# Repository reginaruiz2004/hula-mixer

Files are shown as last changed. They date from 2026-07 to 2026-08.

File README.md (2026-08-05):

# Hula Mixer

Low-cost lab mixer built with Arduino Uno, L298N, and a NEMA17 stepper motor.

## Overview

DIY rotary mixer designed as a cost-effective alternative to commercial lab mixers. Built around an Arduino Uno controlling a NEMA17 stepper motor through an L298N driver, with a rocker switch for power control.

## Status

🔧 In progress — motor control validated, working on perfboard assembly and enclosure design.

## Components

- Arduino Uno R3
- L298N motor driver
- NEMA17 stepper motor (17HS4401)
- Illuminated rocker switch (3-pin, SPDT)
- 12V power supply
- Perfboard (10x7cm)

See [BOM.md](docs/BOM.md) for full parts list.

## Progress Log

- **2026-07-30:** Motor control validated with L298N (coil pairing confirmed: Black-Blue, Green-Red). Wiring diagram completed in Tinkercad. GitHub repo created.

### July 31, 2026

**Circuit Design on TinkerCad**

Key steps completed this round:

- Created a complete circuit diagram of Arduino UNO, L298N, and NEMA17 motor.

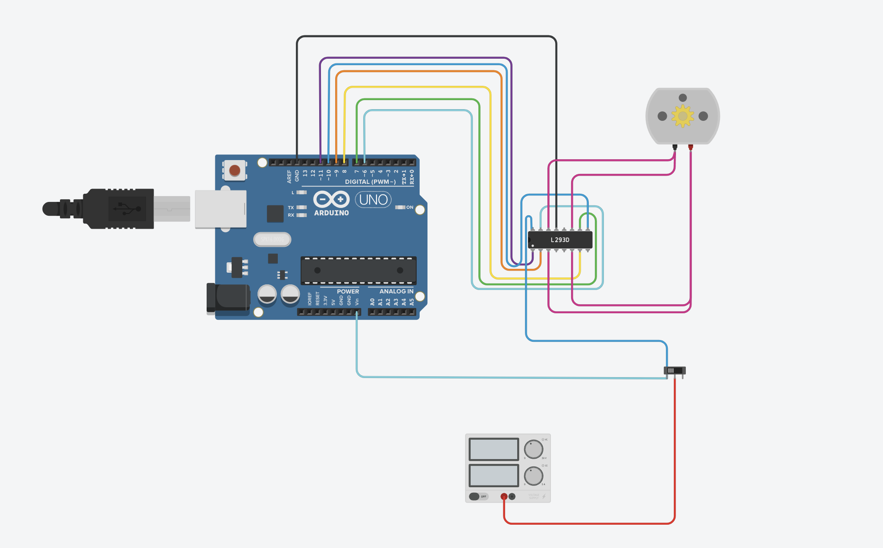
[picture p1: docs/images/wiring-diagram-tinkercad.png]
Circuit Design


### August 4, 2026

**Wooden base setup**

Key steps completed this round:

- Got a wooden base to screw in all of the hula mixer pieces.
- Drilled holes on the wooden base.
- Screwed in each hula mixer piece.
- Using hot glue, I stuck together the other electrical components like the L298N and the Arduino UNO onto a Perfboard.
- Used zip ties to hold all the coords neatly.
- Designed a 3D piece for the coord casing.

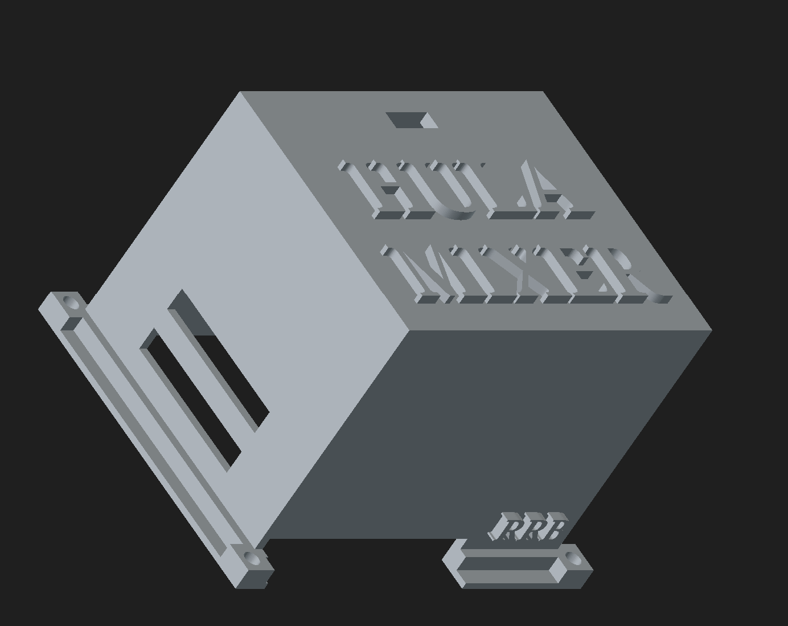
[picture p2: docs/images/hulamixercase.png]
Wiring Case

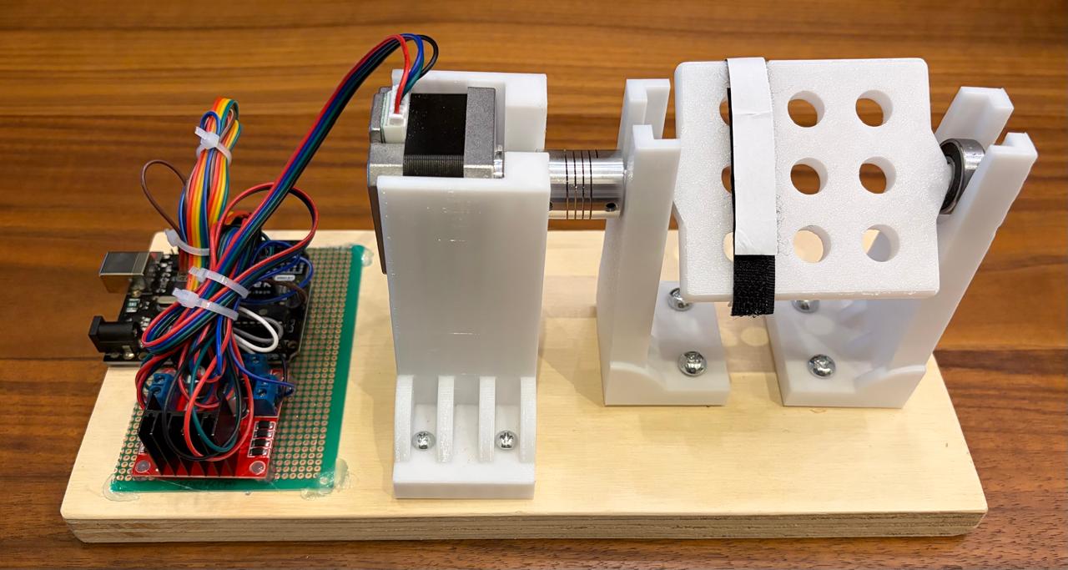
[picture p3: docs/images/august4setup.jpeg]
Hula Mixer Setup

## Documentation

- [Bill of Materials](docs/BOM.md)
- [Design Decisions](docs/DECISIONS.md)
- [Electronics & Wiring](docs/electronics.md)

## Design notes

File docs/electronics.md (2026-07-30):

# Electronics & Wiring

## Arduino Uno → L298N

| L298N Pin | Arduino Uno Pin |
|---|---|
| ENA | D11 |
| IN1 | D9 |
| IN2 | D8 |
| IN3 | D7 |
| IN4 | D6 |
| ENB | D10 |
| GND | GND (shared rail) |

## L298N → NEMA17 Motor

| Motor Wire | L298N Output |
|---|---|
| Black | OUT1 |
| Blue | OUT2 |
| Green | OUT3 |
| Red | OUT4 |

Coil pairs confirmed via multimeter: Black-Blue (Coil A), Green-Red (Coil B).

⚠️ **Do not assume this matches other NEMA17 units** — coil color conventions vary 
by manufacturer/batch. Always verify with a multimeter before wiring.

## Power switch (3-pin illuminated rocker, SPDT)

| Switch Pin | Connects To |
|---|---|
| Common | +12V supply input |
| Terminal 1 | +12V rail (L298N power + Arduino VIN) |
| Terminal 2 | Not used |
| LED pin | GND rail |

Switch is panel-mounted on the enclosure, wired to the perfboard via cable 
(not soldered directly to the perfboard) so the switch can be accessed externally 
while the perfboard stays hidden inside the case.

## Perfboard layout

- Size: 10x7cm, isolated-hole perfboard
- Arduino Uno and L298N mounted side by side
- Two dedicated rows: +12V rail and GND rail, bridged with soldered jumper wire 
  across all connection points on each row
- All components (Arduino VIN, L298N power, switch output) tap into these two rails

## Reference wiring diagram

Built in Tinkercad Circuits (L293D component used as L298N stand-in, since 
Tinkercad's library does not include the L298N specifically).

Tinkercad wiring diagram

## Test code

See [`firmware/hula_mixer.ino`](../firmware/hula_mixer.ino) for the motor test sketch 
(single-direction rotation, used to validate wiring before full implementation).

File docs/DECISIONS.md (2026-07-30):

# Design Decisions

## Driver: L298N over A4988

Chose L298N instead of A4988 (used in Megaruptor) because:
- Mixing does not require microstepping precision — full-step control is sufficient
- Simpler wiring for this use case, no Vref calibration needed
- Already had L298N on hand from initial project attempt

## Arduino: Uno over Nano

Initial attempts used an Arduino Nano, which had persistent unreliability issues — 
traced to counterfeit Nano boards from MercadoLibre containing LGT8F328P chips that 
mimic the ATmega328P bootloader but don't execute code identically. Switched to 
Arduino Uno R3 (Gelek brand) for reliable, consistent behavior.

## Motor coil identification

The NEMA17 motor used in this build has different coil pairing than the one used in 
Megaruptor. Confirmed via multimeter continuity testing:
- **Coil A:** Black - Blue
- **Coil B:** Green - Red

This does NOT match standard color conventions assumed from other NEMA17 units — 
always verify coil pairs with a multimeter before wiring to the driver, rather than 
assuming based on wire color alone.

## Switch wiring (SPDT, 3-pin illuminated rocker)

The switch has 3 terminals: two switching contacts + one LED return pin. Wiring:
- **Common terminal** → +12V power supply input
- **Terminal 1** (switched output) → +12V rail (L298N power + Arduino VIN)
- **Terminal 2** → unused
- **LED pin** → GND rail

Switch is mounted on the enclosure panel (not on the perfboard) and connects to the 
perfboard via cable, to keep the perfboard fully enclosed and hidden.

## Power distribution: shared +12V/GND rails

Perfboard uses two dedicated rows — one for +12V, one for GND — rather than routing 
individual wires from the power source to each component. Simplifies future additions 
(e.g., keypad) by giving them a common power point to tap into.

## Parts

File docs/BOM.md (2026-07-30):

# Bill of Materials

## Electronics

| Component | Spec | Notes |
|---|---|---|
| Arduino Uno R3 | ATmega328P, ATmega16U2 USB chip | Gelek brand confirmed working |
| L298N Motor Driver | Dual H-bridge | |
| NEMA17 Stepper Motor | 17HS4401, 1.7A/phase | Coil pairs: Black-Blue, Green-Red |
| Rocker Switch | 3-pin, SPDT, illuminated | Red, ON/OFF marking |
| Power Supply | 12V, 2A | |
| Perfboard | 10x7cm | Isolated-hole type |
| Faston Terminals | Red (22-18 AWG), 4.8mm or 6.3mm | Confirm switch tab width before purchase |

## Wire

- 20-22 AWG stranded wire (silicone insulation preferred) for switch connections

## Connectors (optional)

- JST-XH 2-3 pin (for detachable switch connection to perfboard)

## Planned / Not Yet Added

- 4x4 matrix keypad (future addition, pending Arduino Uno pin availability)

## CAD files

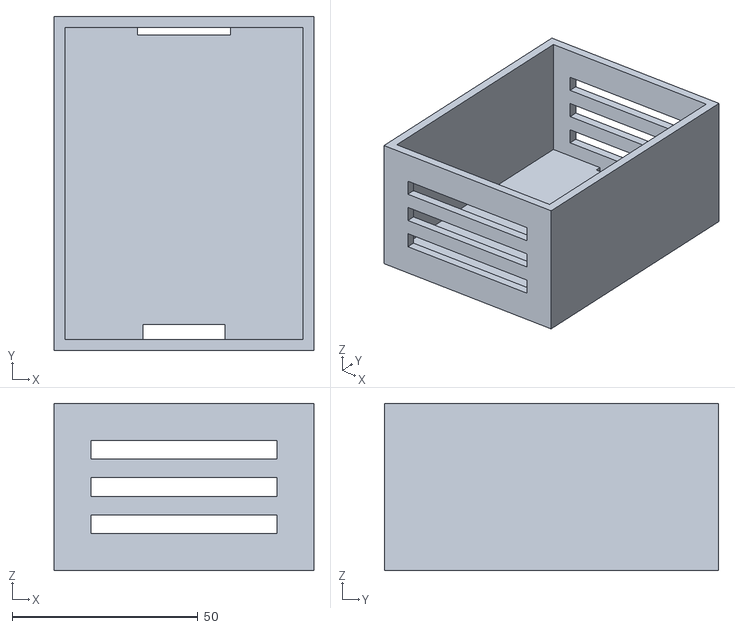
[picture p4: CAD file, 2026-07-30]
STL/electric cover-Body.stl
70.0 x 90.0 x 45.0

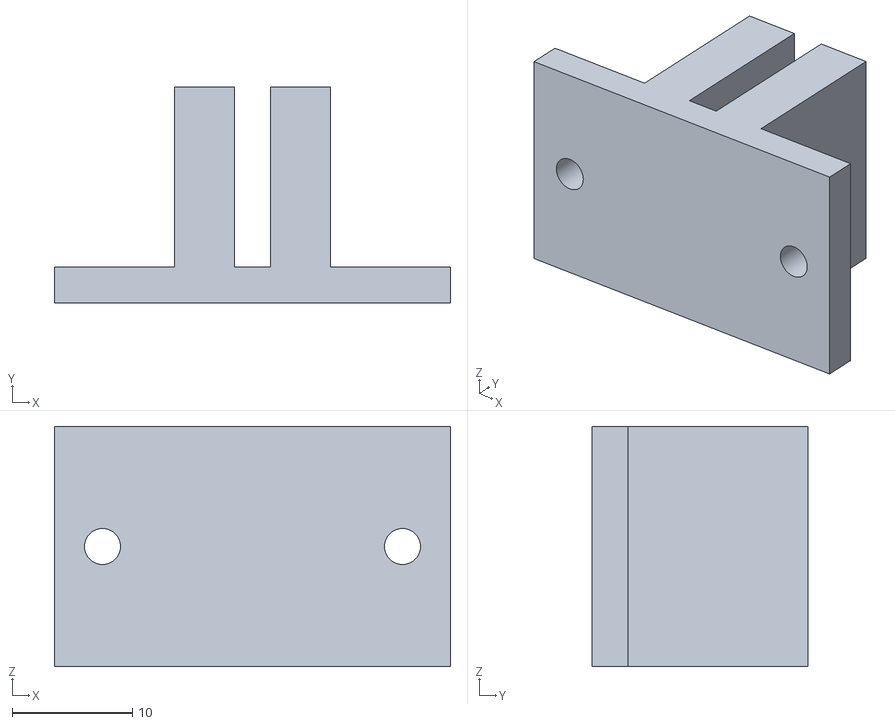
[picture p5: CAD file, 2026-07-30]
STL/electric cover supports-Body.stl
33.0 x 18.0 x 20.0

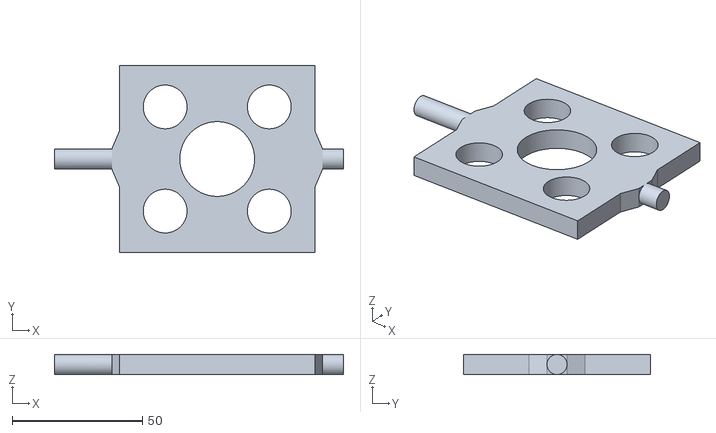
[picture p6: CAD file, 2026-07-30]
STL/grid falcon-Body.stl
111.0 x 71.7 x 7.70

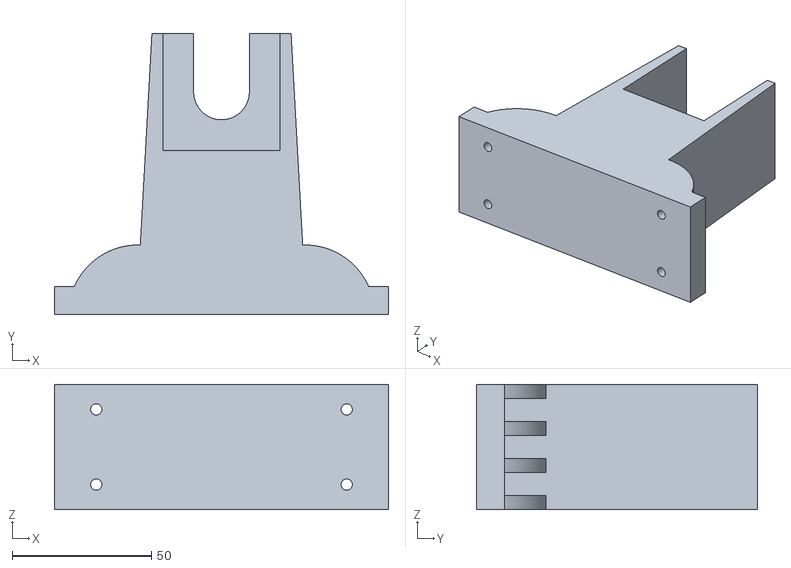
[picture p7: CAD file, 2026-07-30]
STL/motor support-Body.stl
120.0 x 101.0 x 45.0

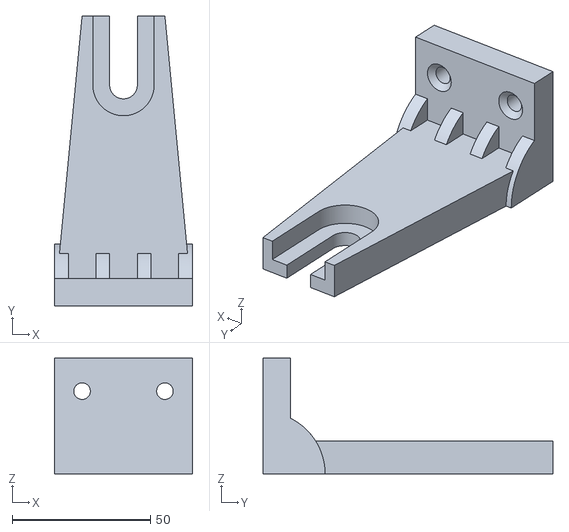
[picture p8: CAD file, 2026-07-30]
STL/support-Body.stl
50.0 x 105.0 x 42.0

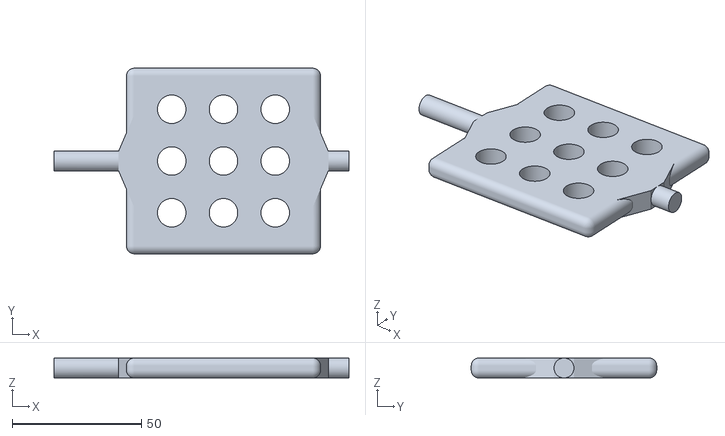
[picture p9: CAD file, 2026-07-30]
STL/grid eppendorf-Body.stl
114.0 x 71.7 x 7.70

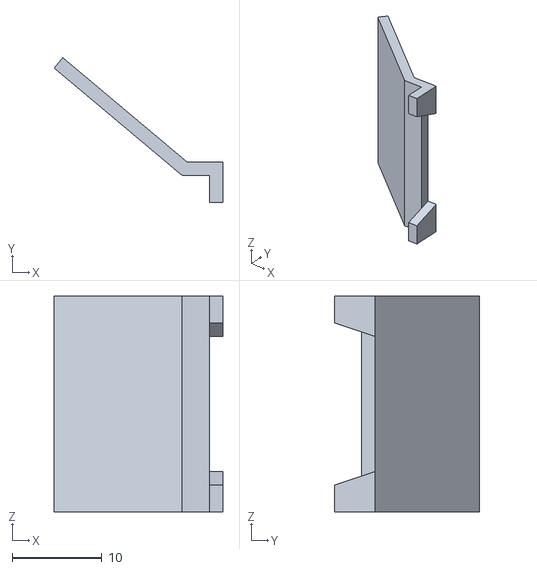
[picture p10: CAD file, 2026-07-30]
STL/screen support-Body.stl
18.8 x 16.1 x 24.0

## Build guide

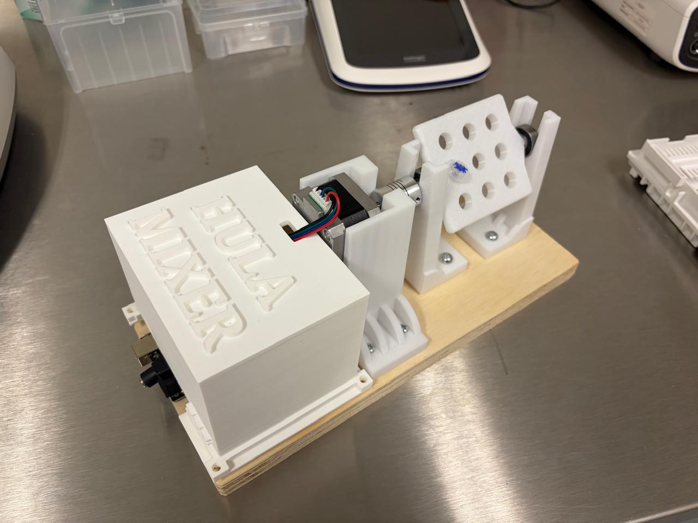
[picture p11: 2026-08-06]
docs/images/finalhardwaresetupaugust5.jpeg

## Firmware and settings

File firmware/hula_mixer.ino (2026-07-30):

/*
 * Hula Mixer - Motor Test Sketch
 * 
 * Validates L298N + NEMA17 wiring before full implementation.
 * Rotates motor one full revolution in a single direction, repeatedly.
 * 
 * Wiring: see docs/electronics.md
 */

#include <Stepper.h>

// Steps per revolution (200 steps = 1.8° per step, full-step mode)
const int stepsPerRevolution = 200;

// Pin order for Stepper object: IN1, IN3, IN2, IN4
// (library expects coil order, not L298N physical pin order)
Stepper myStepper(stepsPerRevolution, 9, 7, 8, 6);

const int ENA = 11;
const int ENB = 10;

void setup() {
  pinMode(ENA, OUTPUT);
  pinMode(ENB, OUTPUT);
  digitalWrite(ENA, HIGH);
  digitalWrite(ENB, HIGH);

  myStepper.setSpeed(60);
}

void loop() {
  myStepper.step(stepsPerRevolution);
  delay(1000);
}

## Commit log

2026-07-30 Add initial documentation and motor test sketch
2026-07-30 Add Tinkercad wiring diagram
2026-07-30 Add 3d printing STL files
    [electric cover supports-Body.stl, electric cover-Body.stl, grid eppendorf-Body.stl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]
